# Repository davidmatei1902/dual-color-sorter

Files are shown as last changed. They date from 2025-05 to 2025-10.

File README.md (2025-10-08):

# Dual Color Sorter

An automated conveyor-belt system that classifies objects by color (e.g., orange or blue) and redirects them using a motorized paddle. This educational prototype uses an ultrasonic distance sensor and a color sensor to detect, classify, and sort objects in real time.

## Overview

The Dual Color Sorter is a microcontroller-based prototype that demonstrates the core principles of automated sorting in logistics and manufacturing. It uses basic sensors and actuators controlled by an Arduino Uno to classify and redirect small objects based on color.

## Features

- **Automatic object sorting** based on detected color
- **Color classification** using the TCS230 sensor (default: orange vs. blue)
- **Ultrasonic object detection** with HC-SR04
- **Motorized paddle** for redirection (left for orange, right for blue)
- **Continuous loop logic** with a start/stop button
- **Modular and educational design**, suitable for prototyping and teaching

## Hardware Components

| Component | Description |
|---|---|
| Arduino Uno | Main microcontroller |
| TCS230 | Color sensor for RGB color detection |
| HC-SR04 | Ultrasonic sensor for object presence detection |
| GA12-N20 DC Motors  | Drives both the conveyor belt and paddle mechanism |
| L298N Motor Driver  | Dual H-bridge to control DC motors |
| LM2596 Buck Converter | Power regulation (6V from 9V battery) |
| Conveyor Belt | Transports objects through the system |
| Power Supply | Two 9V batteries |

##   Project Overview

<p align="center">
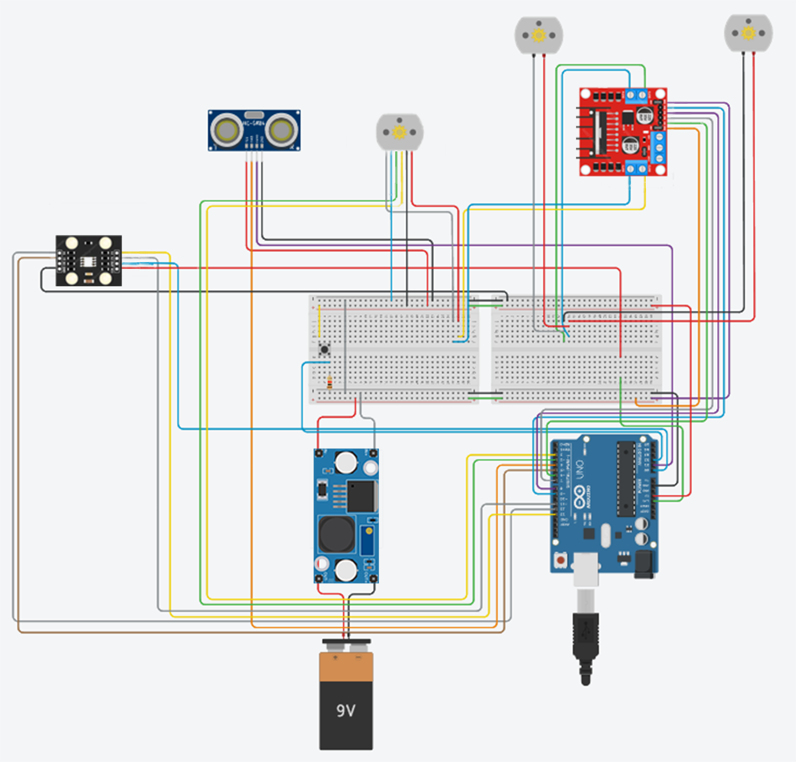
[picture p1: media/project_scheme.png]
Project Overview
  
</p>

<p align="center"><em>Figure : Overview of the Dual Color Sorter system, showing its components and layout.</em></p>

## How It Works

1. The user presses a button to start the conveyor belt.
2. An object is detected by the ultrasonic sensor.
3. The conveyor belt stops once the object reaches the color detection zone.
4. The TCS230 sensor reads the object's color.
5. The Arduino compares the RGB values to reference data:
   - If **orange**, the paddle redirects the object to the left.
   - If **blue**, the paddle redirects it to the right.
6. The belt pauses briefly, then resumes for the next object.

This cycle repeats for continuous sorting.

## Calibration

The color sensor is calibrated in four steps:
1. Place the sensor on a **white** surface and press the button.
2. Repeat for **black**, **blue**, and **orange** surfaces.
3. The system stores RGB thresholds and calculates distances to identify color in real-time.

## Pseudocode Logic

```plaintext
Function setup:
    Initialize pins

Function loop:
    Calculate how long the button was pressed
    if pressed time < 2s:
        if not in calibration mode:
            if system is off:
                Turn on system
            else:
                Turn off system
        else:
            Process calibration step
    else:
        Start calibration mode

    if system is on:
        Start conveyor belt
        Calculate distance to object
        if object reached paddle area:
            Stop conveyor belt
            Detect color
            if color is orange:
                Rotate paddle left
            else if color is blue:
                Rotate paddle right
            else:
                Resume conveyor belt
    else:
        Stop conveyor belt
```

## Technical Specifications

- **Conveyor Dimensions:** 26 × 4 × 4 cm
- **System Dimensions:** 54 × 25 × 24 cm (closed), 75 × 68 × 24 cm (open)
- **Max Object Size:** 3 × 3 × 4 cm
- **Power Supply:** 2 × 9V batteries
- **Operating Temperature:** 10–40°C
- **Estimated Power Consumption:** 35W

## Authors

- **Badea Cătălin-Gabriel** — Hardware design, 3D modeling, wiring, documentation
- **Atudosiei Andrei Cristian** — Firmware development, calibration algorithm, optimization
- **Matei David** — Circuit integration, assembly, component sourcing, video editing

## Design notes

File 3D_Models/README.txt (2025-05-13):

It is possible that the models in the 
folder are not at an absolutely perfect scale, 
as they may have been slightly adjusted—either 
during export or within the printer's software.

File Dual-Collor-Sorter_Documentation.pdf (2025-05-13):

# Dual Color Sorter

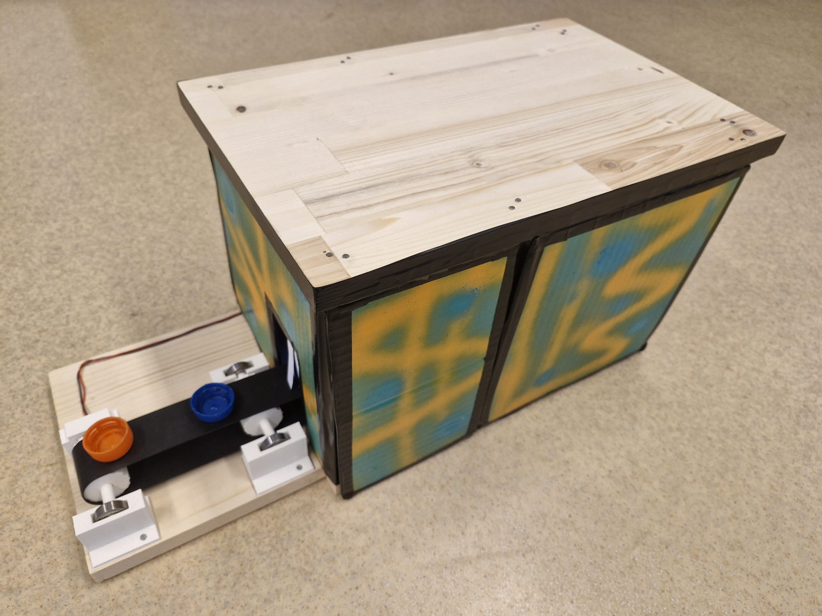
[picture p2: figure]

Abstract

This project presents an automated object sorting system implemented with a conveyor belt. The system is designed to identify and sort objects based on their color (orange or blue) using a combination of an ultrasonic distance sensor and a color sensor. A paddle mechanism redirects objects to appropriate paths based on their detected color. This document outlines the design, implementation, and testing of the system, along with its potential applications in industrial automation.

Authors:
Badea C˘at˘alin-Gabriel, Matei David, Atudosiei Andrei Cristian

Date: May 2025

Color Sorter Project | Badea Gabriel, Atudosiei Andrei, Matei David

## Contents

1 Domain Overview | 3
2 Project Objectives | 5
3 Implementation | 6
4 Testing and Calibration | 11
5 Problems Encountered | 12
6 Potential Improvements and Future Extensions | 13
7 Conclusion | 14

## 1 Domain Overview

### 1.1 Introduction

The domain of this project is firmly situated within intelligent transportation systems (ITS), with a specific focus on automated object classification and routing. This system demonstrates the principles of smart logistics by using a conveyor belt to sort objects based on their color—specifically identifying and separating orange and blue items.
By integrating basic color-based classification, the system mimics intelligent transport technologies where real-time decisions are made based on sensor input. This leads to improved accuracy, reduced manual intervention, and increased efficiency in the handling and routing of physical items within broader transportation and logistics frameworks.

### 1.2 The Importance of Sorting Systems

Sorting systems are fundamental to the efficient handling and management of data, objects, and processes across a wide range of industries. Whether applied in computer science, logistics, manufacturing, or administration, an effective sorting mechanism improves clarity, reduces processing time, and enhances user experience.
By organizing elements based on defined criteria—such as alphabetical order, numerical value, priority, or category—sorting enables faster retrieval, better data analysis, and streamlined operations. In large-scale systems, such as databases or automated warehouses, sorting becomes critical for performance optimization and scalability.
Moreover, it contributes to error reduction and supports automation by establishing a predictable structure. As the amount of information and complexity of workflows continue to grow, the role of sorting systems becomes increasingly vital for ensuring order, efficiency, and informed decision-making.

### 1.3 Similar Existing Solutions

Modern industrial sorting systems increasingly rely on advanced technologies to improve accuracy, speed, and flexibility. Table 1 highlights some of the most commonly used methods and their applications.

Technology | Application
Machine vision | Cameras and image processing for sorting based on color, shape, or size
AI and machine learning | Pattern recognition for complex or variable sorting tasks
RFID technology | Wireless identification and sorting of tagged items

Table 1: Advanced technologies in industrial sorting systems

These technologies are widely used in industries such as manufacturing, recycling, and logistics. Machine vision handles visual analysis, AI enables smarter decisions based on learned patterns, and RFID offers efficient tracking and categorization without visual input.

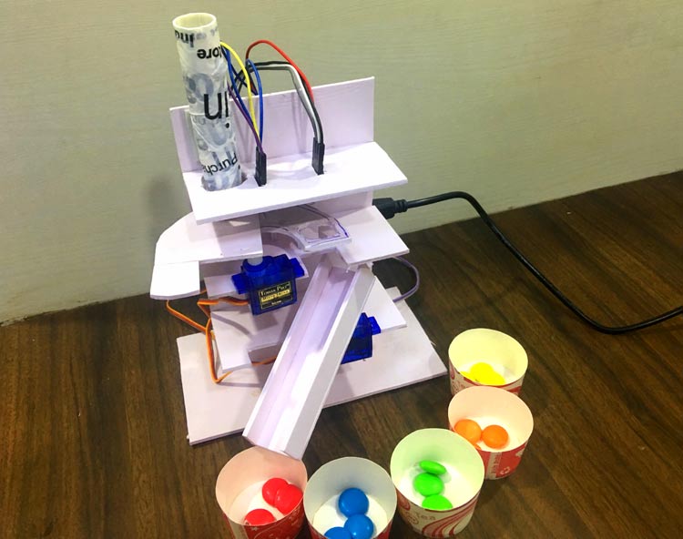
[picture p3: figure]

Figure 1: Multiple Color Sorter System Machine

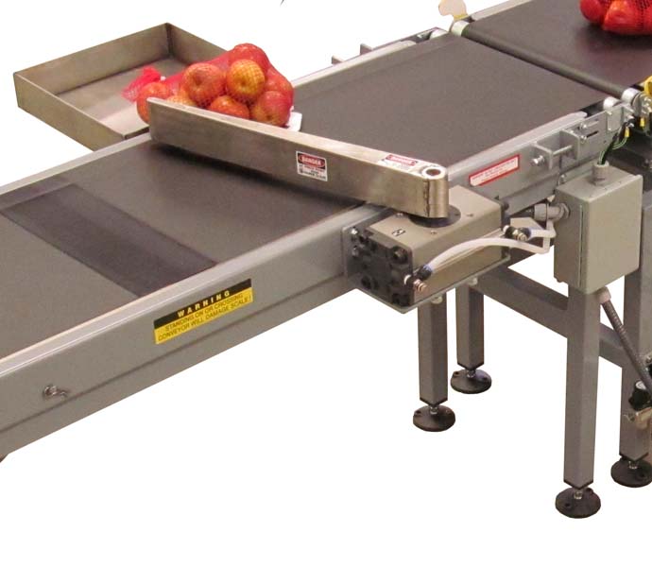
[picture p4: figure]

Figure 2: Apple Sorter with Mechanical Redirectors

### 1.4 Our Approach

Our approach is a simplified prototype inspired by industrial sorting systems. While commercial systems rely on advanced technologies, our focus is on color-based sorting using basic sensors and mechanical actuation.
Created as a didactic prototype, this system aims to teach and experiment with the core principles of automated sorting. Using an ultrasonic sensor for detection and a color sensor for classification, objects are sorted based on their color, with a DC motor controlled paddle redirecting them accordingly.
Though simpler than industrial solutions, our approach serves as a foundation for learning and exploring automated sorting concepts. Furthermore, the colored objects used in this project can simulate containers or casings for items of interest, such as pills, electronic components, or food products. This abstraction allows the system to be relevant in various practical scenarios, including pharmaceutical packaging, component assembly lines, or quality control in food processing. However, the current paddle-based mechanism might be better replaced with a gentler alternative to avoid damaging sensitive items.

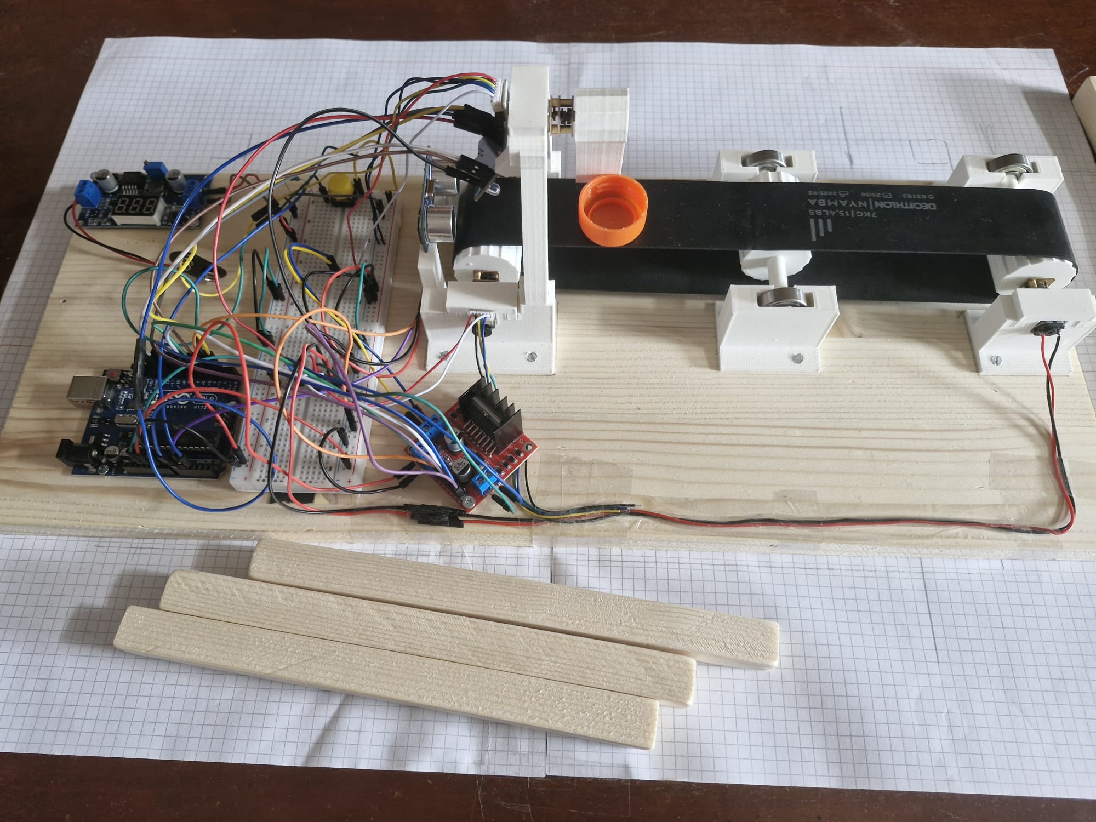
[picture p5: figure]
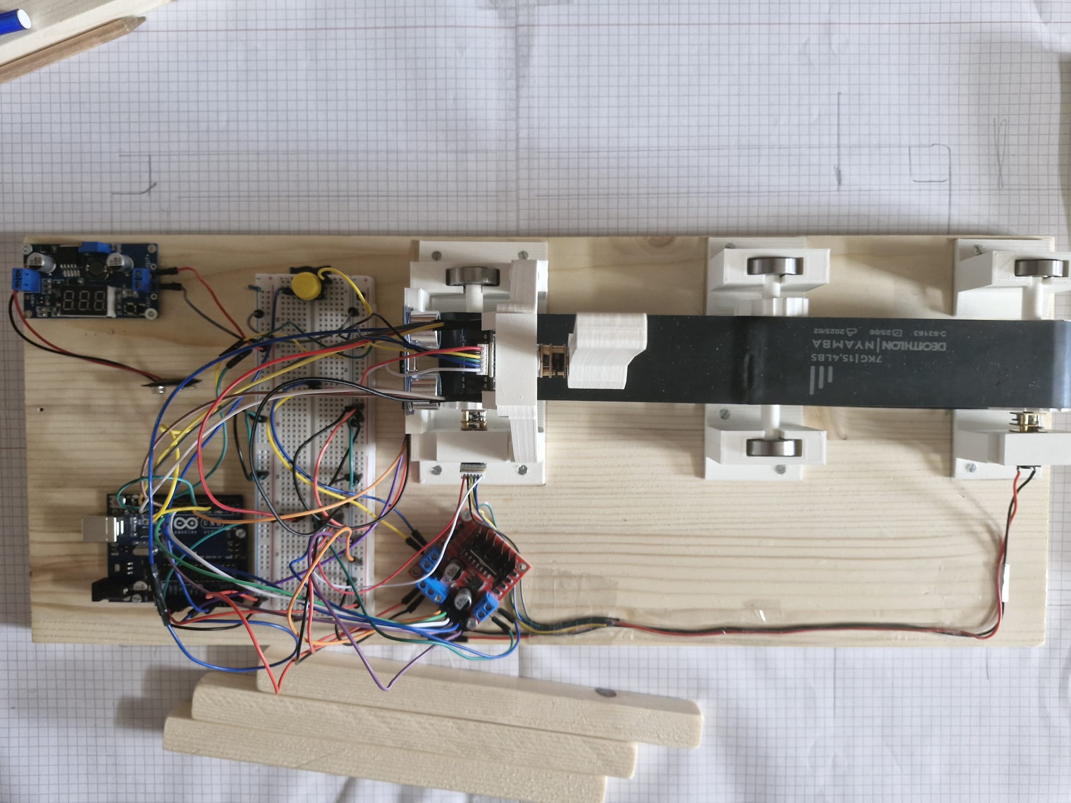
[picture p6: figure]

Figure 3: Wiring Closer View | Figure 4: Wire Top View

## 2 Project Objectives

The development of our automated object sorting system is guided by the following key objectives:

Objective 1: Conveyor-Based Transport System Development

- Design and implement a reliable conveyor belt mechanism
- Ensure smooth and consistent object movement
- Configure appropriate speed for accurate detection and sorting

Objective 2: Precise Color Detection Implementation

- Integrate the TCS230 color sensor for accurate color identification
- Develop algorithms to differentiate between orange and blue objects
- Calibrate the sensor for optimal performance under varying lighting conditions

Objective 3: Automated Object Redirection Mechanism

- Design an efficient paddle actuation system
- Program the rotary motor for precise angular positioning using an encoder
- Ensure reliable sorting with minimal errors

Objective 4: Synchronized Process Control

- Implement the HC-SR04 ultrasonic sensor for accurate object detection
- Create timing sequences for coordinated operation of all system components
- Develop robust control logic for continuous operation

Objective 5: System Optimization and Performance Validation

- Conduct comprehensive testing under operational conditions
- Measure and improve sorting accuracy rates
- Fine-tune timing parameters for maximum throughput

These objectives serve as the foundation for developing a functional, efficient, and reliable color sorting system applicable to small-scale industrial environments where rapid and precise object handling is required.

## 3 Implementation

### 3.1 General Description

The project consists of an automated object sorting system on a conveyor belt, designed to sort two types of colors, which can be configured depending on the system’s calibration. Although the system can be adjusted to detect and sort any two colors, throughout this project we will focus on the case of sorting orange and blue objects.
The system operates through the following process:

### 1. Pressing a button activate/deactivates the conveyor belt, which is powered by two

motors and moves objects smoothly along its path.

### 2. Objects reach a detection zone where an HC-SR04 ultrasonic distance sensor is

positioned.

### 3. When an object reaches the predetermined distance threshold, the belt automat-

ically stops.

4. The TCS230 color sensor identifies its color.

### 5. Based on the detected color, a paddle operated by another GA12 N20 6V motor

redirects the object:

- Orange objects are directed to the left path
- Blue objects are directed to the right path

### 6. After redirection, the system pauses for approximately ? second to ensure com-

plete processing.

7. The conveyor belt resumes operation to transport the next object.

This automated cycle continues, enabling efficient and precise sorting of objects by color. The system’s design emphasizes simplicity and reliability.

### 3.2 System Components

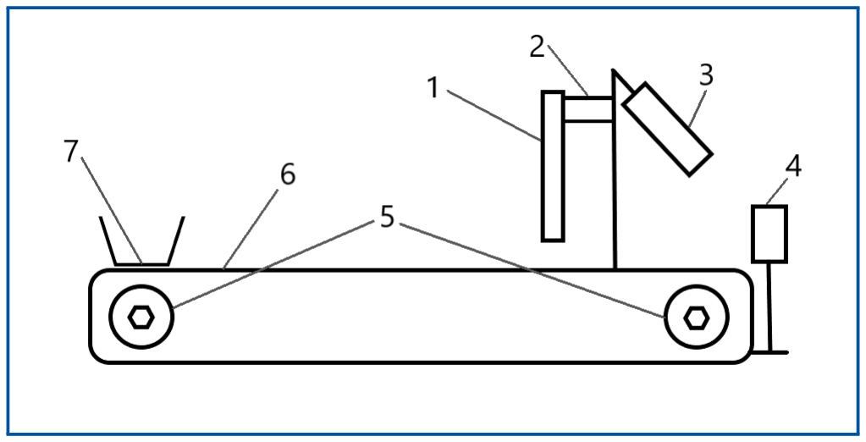
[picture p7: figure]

Figure 5: Structure Diagram

Above, a diagram outlines the structure of the project and below there is a list of the components used, along with a table regarding the key system components and their functions.

No. | Component Name
1 | Paddle
2 | DC-motor (Paddle Controller)
3 | Color Sensor
4 | Distance Sensor
5 | DC-motors (Belt Controllers)
6 | Conveyor Belt
7 | Object to be sorted

Table 2: List of system components by number and name

Component | Type/Model | Function
Conveyor Belt | Dual-motor driven | Transports objects through the sorting system
Distance Sensor | HC-SR04 Ultrasonic | Detects object presence and stops the conveyor belt in the right position
Color Sensor | TCS230 | Identifies the color of objects (orange vs. blue), sending the signal to the microcontroller
Motor Driver | L298N | Dual H-bridge driver for controlling both the conveyor belt and paddle DC motors
Buck Convertor | LM2596 | Adjustable step-down (buck) converter that pro- vides a stable 6V supply from the 9V battery
Actuators | 3 × GA12-N20 6V DC-motor | Controls the paddle for object redirection as well
| | as the conveyor belt
Control Unit | Arduino UNO Microcontroller | Processes sensor data and controls system com- ponents
Power Supply | 2 × 9V Battery | Provides electrical power to all system compo-
| | nents, including the conveyor belt

Table 3: Key system components and their functions

Note that the box can be opened on any side, except for the front, to provide easy access to the circuits and wires inside. This design allows for convenient maintenance and modifications, ensuring that all components are accessible without disturbing the main structure of the system.

### 3.3 Electrical Circuit Design

In this section, the electrical circuit design of the sorting system is presented. The system utilizes multiple components that work together to process data and control the actuators for object sorting. Below is a simplified block diagram that shows how these components are interconnected.
At the core of the system is the Arduino microcontroller, which processes data from the sensors and controls the actuators. The ultrasonic distance sensor is connected to the Arduino and is powered with 5V from it. The color sensor is also connected to the Arduino, but it operates at 3.3V. The Arduino controls the motors through an H-bridge. The H-bridge drives two motors that control the conveyor belt simultaneously and one motor for the paddle mechanism, which redirects the objects. The motors are powered with 6V from a buck converter, which steps down the 9V battery supply to 6V (the operating voltage of the motors). The Arduino itself is powered by a separate 9V battery to ensure proper functionality and to prevent the higher current draw from the motor line from damaging the microcontroller.
The block diagram below illustrates the overall flow of power and control signals within the system.

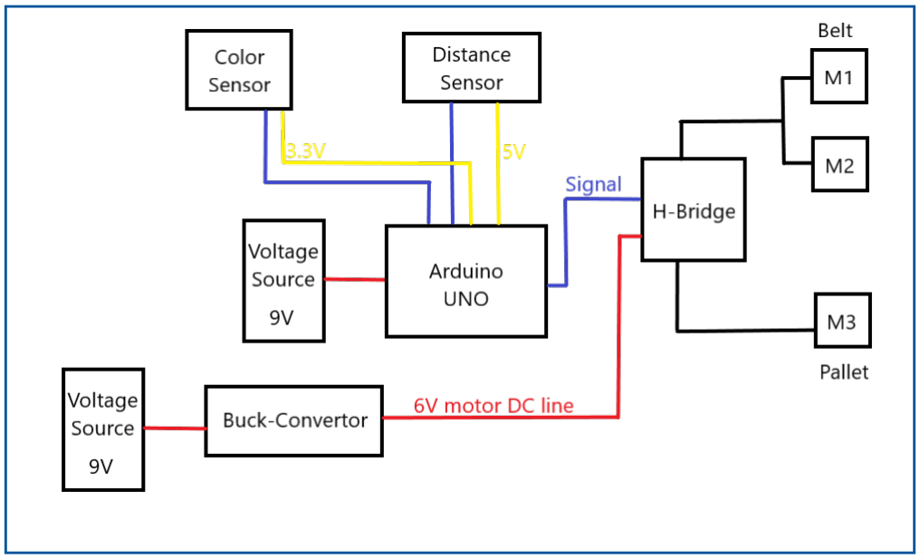
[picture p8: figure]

Figure 6: Block diagram of the sorting system

Following this section, the detailed circuit schematic is provided, showing the exact wiring of each component and how they are physically connected to one another.
It is important to note that the circuit includes a button designed to stop the conveyor belt, allowing for debugging or turning off the system when not in use.


Figure 7: Detailed wiring diagram of the system

### 3.4 Technical Specifications

Parameter | Specification
Conveyor Length/Width/Height | 26 cm / 4 cm / 4 cm
Total System Dimensions | 54 cm x 25 cm x 24 cm (L x W x H)
Total System Dimensions Needed (open) 75 cm x 68 cm x 24 cm (L x W x H)
Maximum Object Size | 3 cm × 3 cm × 4 cm
Power Consumption | 35W
Operating Temperature | 10-40°C
Power Supply | 2 x 9V Battery

Table 4: System technical specifications

### 3.5 Programming and Microcontroller Code

In this section, the programming logic of the sorting system is presented, focusing on the microcontroller code. The Arduino is responsible for processing the data from the sensors, making decisions based on the input, and controlling the actuators to sort the objects.
The code is written in C++ using the Arduino IDE, and it communicates with the various system components, including the ultrasonic distance sensor, color sensor, and motors. Algorithm 1: Main logic for the color sorting system
1 setup Initialize pins;
2 loop Calculate how long the button was pressed;

### 3 if pressed time less than 2s then 4 if not in calibration mode then 5 if system is off then

6 Turn on system;

### 7 else

8 Turn off system;

### 9 end 10 else

11 Process calibration step;

### 12 end 13 else

14 Start calibration mode;

### 15 end 16 if system is on then

17 Start conveyor belt;
18 Calculate distance to object;

### 19 if object reached paddle area then

20 Stop conveyor belt;
21 Detect color;

### 22 if color is orange then

23 Rotate paddle left;

### 24 else 25 if color is blue then

26 Rotate paddle right;

### 27 else

28 Resume conveyor belt;

### 29 end 30 end 31 end 32 end 33 else

34 Stop conveyor belt;

### 35 end

This code is a basic framework for reading sensor data and triggering actions based on specific conditions.

## 4 Testing and Calibration

### 4.1 TCS230 Color Detector

### 4.1.1 Calibration Process Structure

Calibration is divided into four stages: white, black, blue, and orange.

- Stage 1 (White): The user places the sensor on a white surface and presses the button. The system reads the Red, Green, and Blue values and stores them in variables. After a short button press, it advances to the next stage.
- Stage 2 (Black): The user places the sensor on a black surface and presses the button. The system reads and saves the RGB values. After a short press, it moves on.
- Stage 3 (Blue): The user places the sensor on a blue surface and presses the button. The system reads and saves the RGB values. Then proceeds.
- Stage 4 (Orange): The user places the sensor on an orange surface and presses the button. The system reads and saves the RGB values. Calibration is then complete.

### 4.1.2 Setting Color Thresholds

For each color component (Red, Green, Blue), the minimum and maximum thresholds are calculated from the white and black readings:

Red: pragRosuMin, pragRosuMax

Green: pragVerdeMin, pragVerdeMax

Blue: pragAlbastruMin, pragAlbastruMax

Values outside these ranges are considered “unknown.”

### 4.1.3 Color Distance Calculation

During object detection, the system compares the sensed RGB values to the calibrated blue and orange references using:

distance = (r1 − r2)

2 + (g1 − g2)

2 + (b1 − b2)

2

If the distance to orange is less than the distance to blue, the color is detected as orange; otherwise it is detected as blue.

### 4.1.4 Calibration Completion

After all four stages, the flag senzorCalibrat = true is set and the user is notified. The system is now ready for normal operation.

### 4.2 HC-SR04 Ultrasonic Sensor

To test the HC-SR04, a simple Arduino sketch triggers the sensor continuously, measures the echo return time, computes the distance, and prints the results to the serial monitor. Real-time readings allow verification of the sensor’s accuracy.

### 4.3 DC Motors

### 4.3.1 Basic DC Motor Test

An Arduino sketch was used to spin the motors first in one direction and then in reverse, confirming proper wiring and operation.

### 4.3.2 DC Motor with Encoder (CGM12-N20VA-8200E)

For precise one-revolution control, the encoder’s pulse count per full rotation was calibrated:

Encoder Overview The encoder emits pulses (“ticks”) proportional to shaft rotation.

Estimating Pulses per Revolution Based on the motor’s gear ratio and encoder spec, an initial pulse estimate was made.

Testing and Adjustment A sketch rotated the motor while counting ticks. After each trial, the pulse count was tweaked until one commanded revolution matched one full turn.

Finalizing Calibration The correct tick count was hard-coded into the program so that each “full revolution” command yields precise rotation.

## 5 Problems Encountered

During the development of our project, we encountered a series of technical and practical challenges that required iterative problem-solving and adaptation. Below is a summary of the most significant issues and how we addressed them:

- Color sensor instability: Initially, the color sensor did not function reliably. We discovered it was extremely sensitive to minor changes in ambient lighting. To address this, we built a small enclosure around it to maintain consistent lighting conditions.
- Encoder setup difficulties: It took us some time to properly understand and use the rotary encoder. One of the main issues was that it only worked correctly when connected to pins 2 and 3 of the Arduino, which limited our initial wiring options.
- Circuit redesign: We had to completely rebuild the circuit once in order to optimize pin usage. This allowed us to support all the required functionalities more effectively.
- Power supply decision: Finding a suitable power supply was a challenge. In the end, we chose to use a battery, as it offered a more compact and portable solution, and it fit the educational purpose of the project.
- 3D printing issues: The 3D-printed parts did not always match the exact dimensions due to plastic expansion and shrinkage. As a result, we had to reprint several components before achieving the desired fit and functionality.
- Belt selection: It took us some time to find a belt that was suitable for our design and functional requirements.

## 6 Potential Improvements and Future Extensions

While the current prototype demonstrates the core principles of automated color-based sorting, there are several clear avenues to enhance its performance, flexibility and educational value. Key directions for future work include:

- Advanced Color Detection: Upgrade from a simple color sensor to a multi-channel spectral sensor (e.g. TCS34725) or integrate a camera + OpenCV pipeline to sort dozens of hues and even shapes.
- LCD Feedback Display: Integrate an LCD module to present real-time calibration progress—showing each stage (white, black, blue, orange)— as well as continuously display the detected color along with a running count of how many times each color has been identified.
- Modular Mechanical Design: Design interchangeable paddles, adjustable guide rails and expandable conveyor segments to handle different object sizes or multiple lanes in parallel.
- Power Management: Move from 9V batteries to rechargeable Li-ion packs or a smart buck/boost converter with voltage/current monitoring and power-saving modes.

For a future version of the system (v2.0), an important improvement would be the addition of a second sorting paddle mounted on a separate support arm. This would enable the system to handle up to four distinct object categories based on color, instead of the current binary classification.

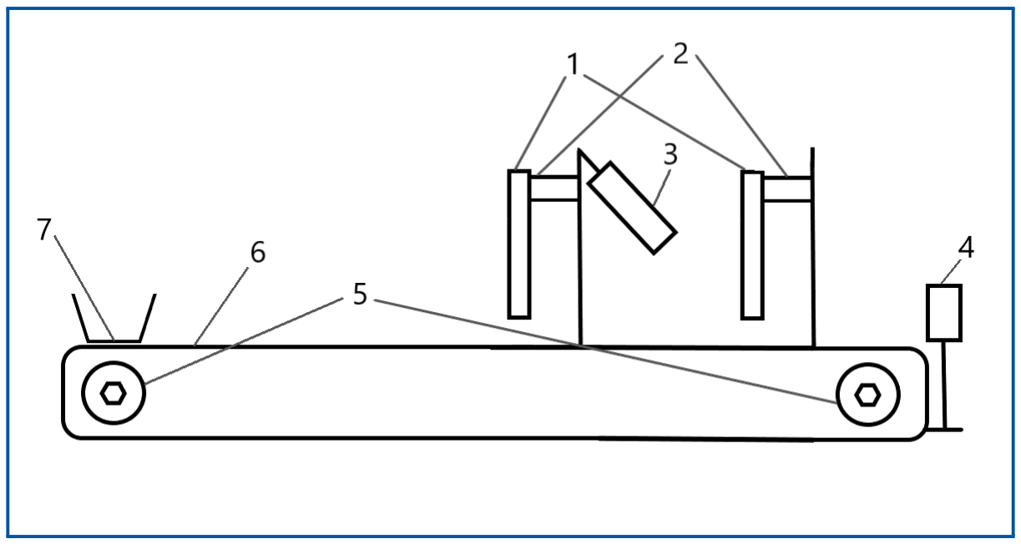
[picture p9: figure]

Figure 8: Structure Diagram V2.0

Furthermore, we considered replacing the battery-based power supply with a stable external power source to ensure longer operating times and improved reliability.
However, due to time constraints and prototyping limitations, these enhancements were not implemented in the current iteration.

## 7 Conclusion

The automated color sorting system successfully demonstrates the application of sensor technology and mechanical actuation. The system reliably sorts orange and blue objects with high accuracy and reasonable throughput.

### 7.1 Individual Contributions

Badea C˘at˘alin-Gabriel:

- Coordonated the whole project
- Designed the circuit and structure of the machine
- Modeled and 3D-printed the support pieces
- Worked on wiring the circuit
- Worked on building and painting the structure of the machine
- Contributed to documentation

Atudosiei Andrei Cristian:

- Developed the code uploaded on the microprocessor
- Color detection algorithm development
- Sensor calibration
- Performance optimization and debugging
- Contributed to documentation

Matei David:

- Documented the schematic
- Worked on wiring the circuit
- Worked on building and painting the structure of the machine
- Purchased and supplied all the components required
- Contributed to documentation
- Edited the video regarding the project completion

### 7.2 Bill Of Materials

Listed below are all the components used in the realization and assembly of the automated sorting system, together with their prices and sources of acquisition.

Item | Part Number / Model | Qty | Total (e) Supplier
1. | Rubber Band | 1 | 3.52 | Decathlon (https://www.decathlon.ro/p/set-3-mini-benzi-elastice-din-cauciuc-100/_/R-p-305336)
2. | HC-SR04 | 1 | 2.93 | ElecFreaks (https://www.optimusdigital.ro/en/ultrasonic-sensors/2328-senzor-ultrasonic-de-distana-hc-sr04-compatibil-33-v-i-5-v.html)
3. | TCS230 | 1 | 7.62 | TAOS (https://www.optimusdigital.ro/en/optical-sensors/111-tcs230-color-sensor-module.html)
4. | GA12-N20 with Encoder | 2 | 20.32 | Handson Technology (https://www.optimusdigital.ro/ro/motoare-micro-motoare-cu-reductor/2937-micro-motor-cu-reductor-i-codor-cgm12-n20va-8200e-52-rpm-la-3-v-105-rpm-la-6-v.html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)
5. | GA12-N20 | 1 | 5.11 | Handson Technology (https://www.emag.ro/micro-motor-cu-reductie-dc-6v-30rpm-ga12-n20-ai1083/pd/DVWFTFMBM/)
6. | Arduino Board A000066 | 1 | 11.60 | OptimusDigital (https://www.optimusdigital.ro/en/avr-boards/4561-development-board-compatible-with-arduino-uno-r3-atmega328p-atmega16u2-50-cm-cable.html)
7. | Jumper Wires (Male–Male) | 18 | 1.10 | OptimusDigital (https://www.optimusdigital.ro/en/wires-with-connectors/891-wires-male-male-10p-30cm.html)
8. | Jumper Wires (Male–Female) | 26 | 0.72 | OptimusDigital (https://www.optimusdigital.ro/en/wires-with-connectors/650-fire-colorate-mama-tata-10p.html)
9. | Battery Holder 9V | 1 | 0.28 | OptimusDigital (https://www.optimusdigital.ro/en/battery-holders/20-9v-battery-support.html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)
10. | Through-Hole Resistor 470 Ohm | 1 | 0.02 | OptimusDigital (https://www.optimusdigital.ro/en/resistors/852-025w-470k-resistor.html?search_query=resistor&results=367)
11. | Tactile Push-Button | 1 | 0.43 | OptimusDigital (https://www.optimusdigital.ro/en/buttons-and-switches/1115-white-button-with-round-cover.html)
12. | Power Cable | 1 | 0.76 | XAB3 (https://www.xab3.ro/produse/332cablu-alimentare-arduino)
13. | Bearing 608-2Z Welt | 4 | 4.00 | Herasib (https://www.emag.ro/rulment-608-2z-welt-608-2z-welt/pd/D2SPMDMBM/)
14. | High Performance Battery 9V | 2 | 4.48 | Auchan (https://www.auchan.ro/baterie-alcalina-auchan-high-performance-6lr61-9v-1-bucata/p)
15. | L298N - H-Bridge | 1 | 2.72 | Optimus Digital (https://www.optimusdigital.ro/en/brushed-motor-drivers/145-l298n-dual-motor-driver.html)
16. | LM2596 - Buck Convertor | 1 | 1.00 | Texas Instruments (https://www.optimusdigital.ro/en/adjustable-step-down-power-supplies/805-lm2596-dc-dc-module-with-voltage-display.html)
17. | Verbatim PLA 1.75 mm (750 g) | 1 | 25.00 | Verbatim (https://www.flax.ro/filament-verbatim-pla-1-75mm-1kg-natural-55317-356643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)
18. | Plywood Base | 1 | 3.92 | Leroy Merlin (https://www.leroymerlin.ro/produse/grinzi-lemn/1631/scandura-nerindeluita-lemn-rasinoase-24-x-200-x-4000-mm/122722)
19. | Plywood Poles | 1 | 3.92 | Leroy Merlin (https://www.leroymerlin.ro/produse/grinzi-lemn/1631/rigla-rindeluita-lemn-rasinoase-42-x-42-x-2000-mm/13644)
20. | Plywood Roof | 1 | 4.9 | Leroy Merlin (https://www.leroymerlin.ro/produse/polite-din-pal-lemn/1252/polita-lemn-rasinoase-calitatea-b-800-x-300-x-18-mm/96106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)
19. | Nails | 32 | 0.82 | Leroy Merlin (https://www.leroymerlin.ro/produse/cuie/939/cuie-lemn-3-x-50-mm-1-kg/125857)
19. | Screws | 21 | 1.008 | Leroy Merlin (https://www.leroymerlin.ro/produse/suruburi/942/surub-lemn-cap-inecat-otel-zincat-4.5-x-20-mm-vrac/36231)

Table 5: Bill of Materials

## Total Price: 90.048 e

## References

[1] Electronic | Principles | (Malvino) – https://www.talkingelectronics.com/
Download/Malvino_Electronic-Principles.pdf (https://www.talkingelectronics.com/Download/Malvino_Electronic-Principles.pdf)
[2] Ultrasonic Sensor HC-SR04 and Arduino – Complete Guide – https://howtomechatronics.com/tutorials/arduino/ultrasonic-sensor-hc-sr04/
[3] Good Year Industrial Conveyor Belt - https://goodyearbelts.com/wp-content/uploads/2024/02/New-Industrial-Catalog-2024-FINAL.pdf (https://goodyearbelts.com/wp-content/uploads/2024/02/New-Industrial-Catalog-2024-FINAL.pdf)
[4] Contitech Lightweight Conveyor Belt https://www.goodyearbelting.com/pdf/Contitech_2015_LW_Conv_Belt_Catalog/pdf/Contitech_2015_LW_Conv_Belt_Catalog.pdf (https://www.goodyearbelting.com/pdf/Contitech_2015_LW_Conv_Belt_Catalog/pdf/Contitech_2015_LW_Conv_Belt_Catalog.pdf)

Technical datasheets for every component used in this project are listed below:

[5] HC-SR04 – https://cdn.sparkfun.com/datasheets/Sensors/Proximity/HCSR04. pdf (https://cdn.sparkfun.com/datasheets/Sensors/Proximity/HCSR04.pdf)
[6] TCS230 – https://www.mouser.com/datasheet/2/588/cs230-e33-1214740.pdf
[7] GA12-N20 6V DC Motor – https://www.handsontec.com/dataspecs/GA12-N20. pdf (https://www.handsontec.com/dataspecs/GA12-N20.pdf)
[8] Arduino | Uno | Microcontroller | – | https://docs.arduino.cc/resources/
datasheets/A000066-datasheet.pdf (https://docs.arduino.cc/resources/datasheets/A000066-datasheet.pdf)
[9] 9V Battery (Energizer 522) – https://data.energizer.com/pdfs/522.pdf
[10] Conveyor Belt Catalog (Goodyear, 2024) – https://goodyearrubberproducts.lat/wp-content/uploads/2024-GRP-Conveyor-Belt-Catalog.pdf (https://goodyearrubberproducts.lat/wp-content/uploads/2024-GRP-Conveyor-Belt-Catalog.pdf)
[11] L298N Module – https://www.alldatasheet.com/datasheet-pdf/view/22440/STMICROELECTRONICS/L298N.html (https://www.alldatasheet.com/datasheet-pdf/view/22440/STMICROELECTRONICS/L298N.html)
[12] LM2596 Module – https://www.ti.com/lit/ds/symlink/lm2596.pdf

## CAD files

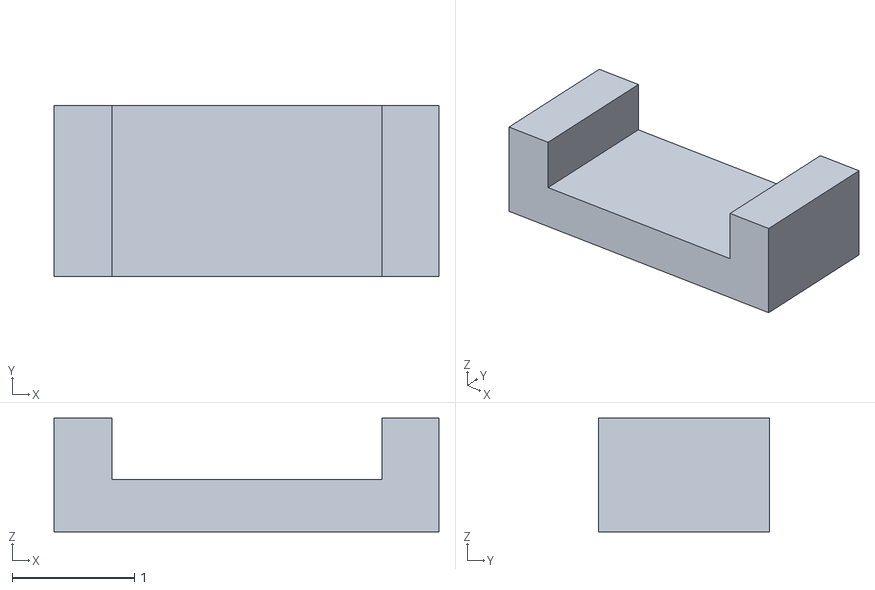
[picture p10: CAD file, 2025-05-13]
3D_Models/clamp.stl
3.16 x 1.40 x 0.931

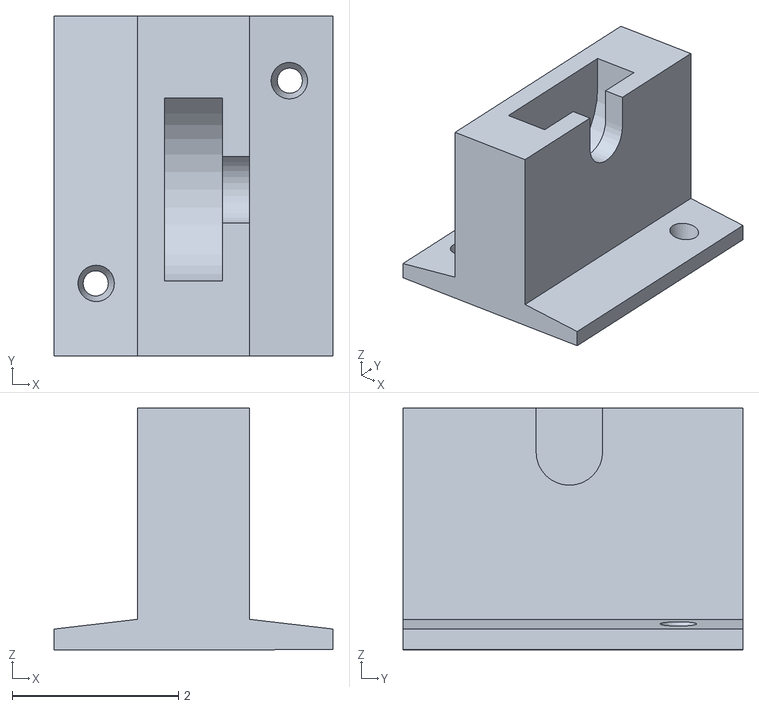
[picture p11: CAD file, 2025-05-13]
3D_Models/structural_frame_1.stl
3.36 x 4.09 x 2.91

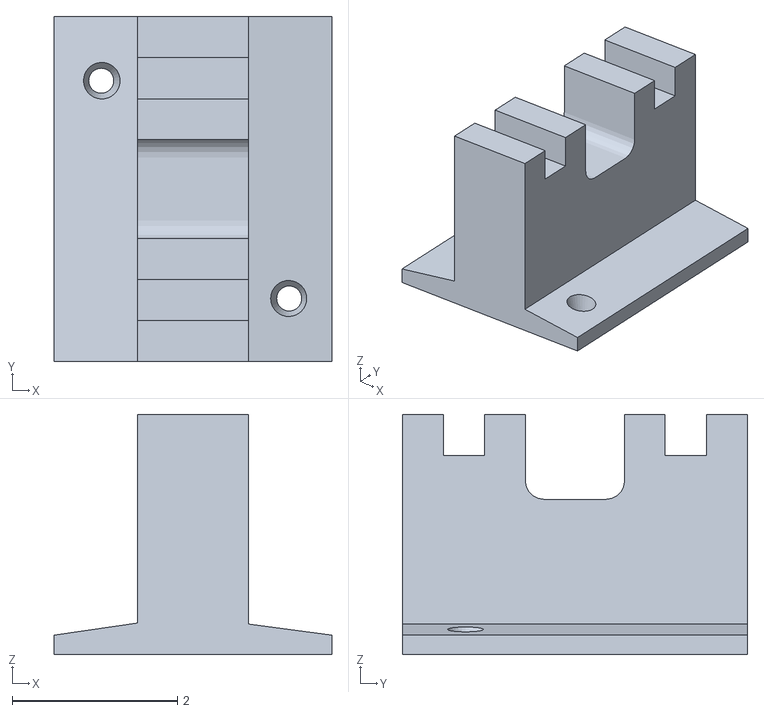
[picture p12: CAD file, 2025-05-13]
3D_Models/structural_frame_2.stl
3.36 x 4.18 x 2.91

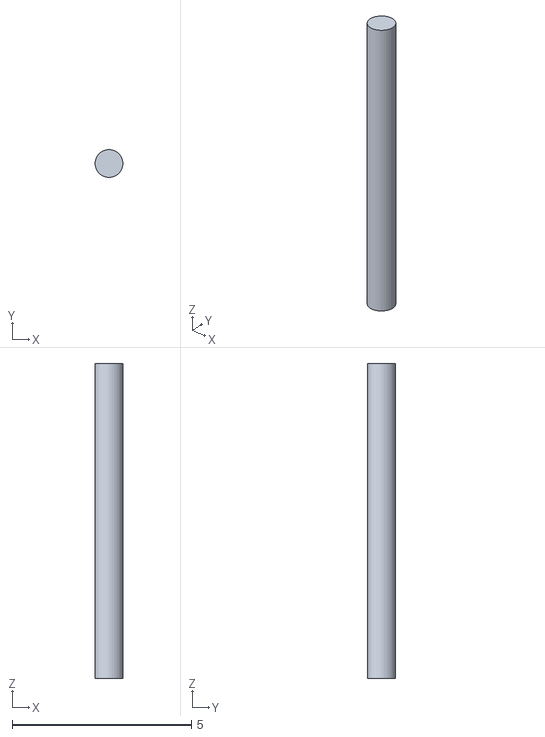
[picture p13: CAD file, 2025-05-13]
3D_Models/shaft_long.stl
0.779 x 0.779 x 8.78

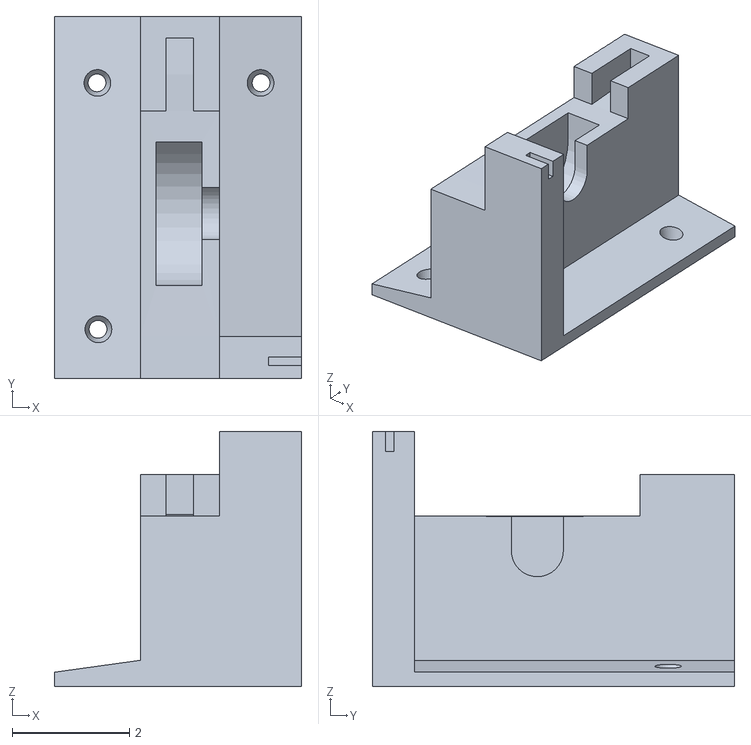
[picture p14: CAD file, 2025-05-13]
3D_Models/structural_frame_3.stl
4.21 x 6.16 x 4.34

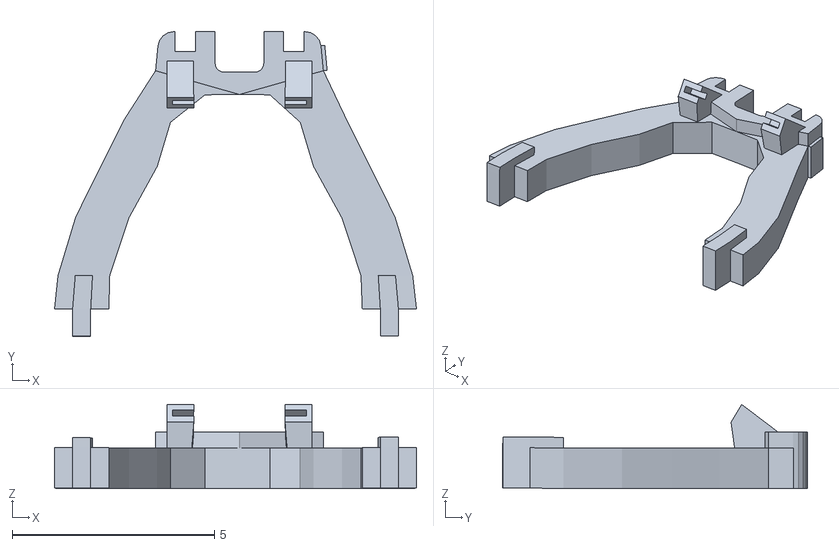
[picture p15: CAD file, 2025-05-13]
3D_Models/ark_support.stl
8.94 x 7.53 x 2.08

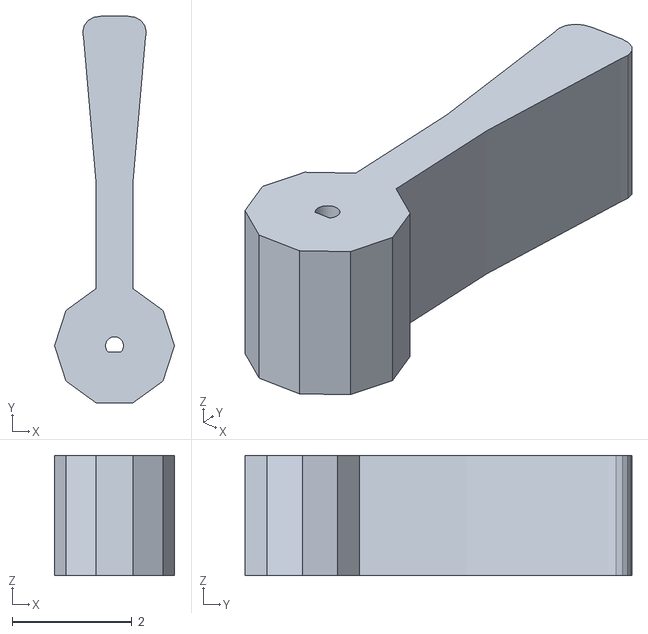
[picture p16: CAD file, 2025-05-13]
3D_Models/peddle.stl
2.00 x 6.44 x 2.00

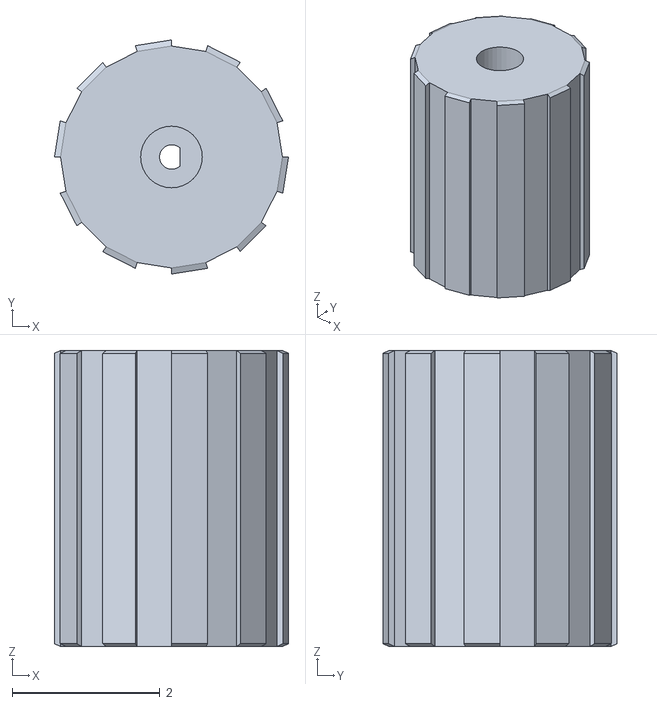
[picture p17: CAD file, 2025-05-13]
3D_Models/tube_support.stl
3.16 x 3.16 x 4.00

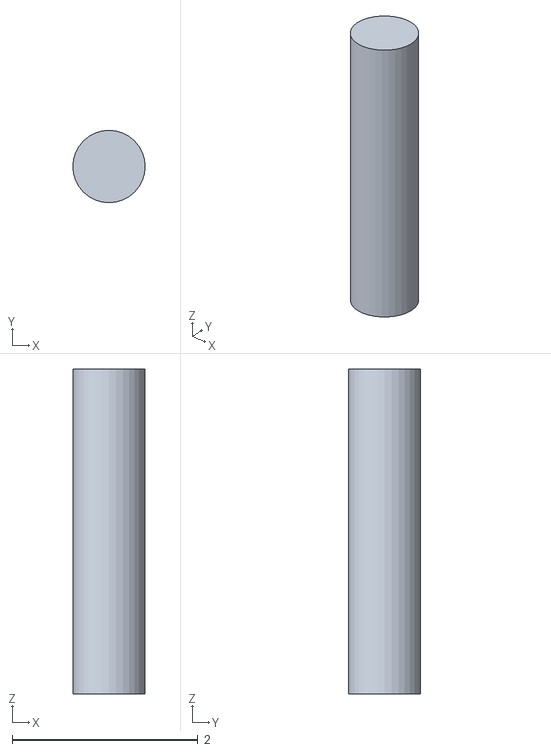
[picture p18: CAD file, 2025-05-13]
3D_Models/shaft_short.stl
0.779 x 0.779 x 3.50

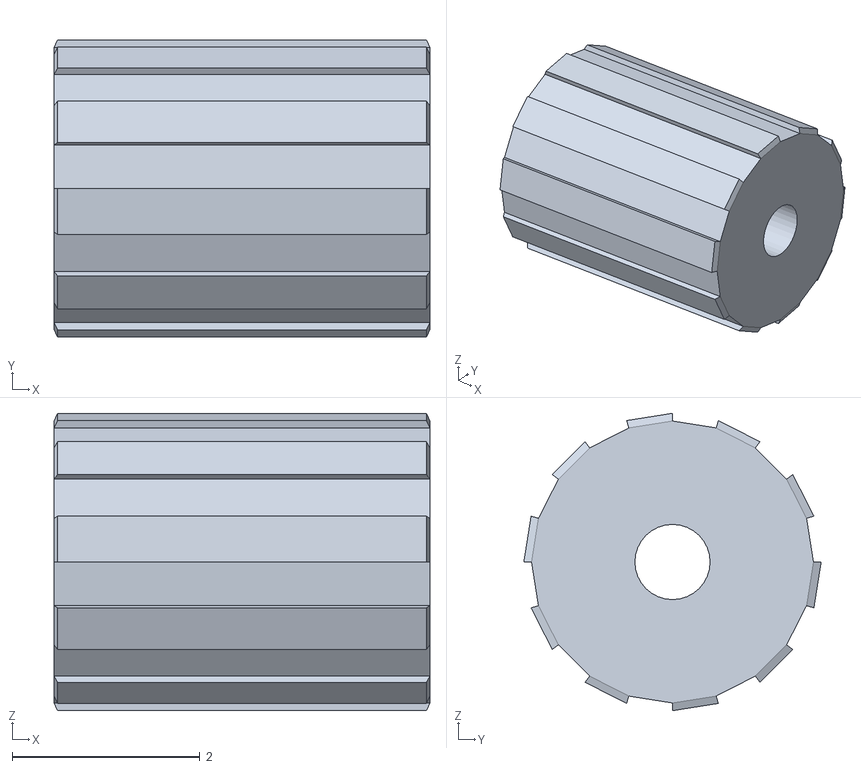
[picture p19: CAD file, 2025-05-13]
3D_Models/tube_support_empty.stl
4.00 x 3.16 x 3.16

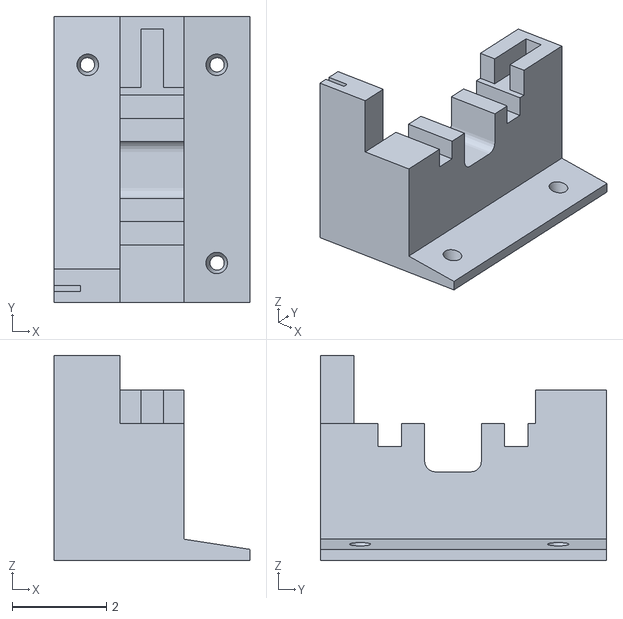
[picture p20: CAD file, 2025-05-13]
3D_Models/structural_frame_4.stl
4.14 x 6.05 x 4.35

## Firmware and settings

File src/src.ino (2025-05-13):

const int IN3 = 8; 
const int IN4 = 9;

const int IN1 = 6;   
const int IN2 = 7;   

const int ENCODER_A_PIN = 2;  
const int ENCODER_B_PIN = 3;  
volatile long encoderTicks = 0;

const int TICKS_PER_ROTATION = 611;  

const int TRIG_PIN = 4;
const int ECHO_PIN = A1;

const int S0 = 12;
const int S1 = 5;
const int S2 = 11;
const int S3 = 13;
const int OUT_COLOR = A0;

const int BUTTON_PIN = A2;

bool running = false;
bool last_button_state = LOW;
unsigned long ultimaApasare = 0;
const unsigned long INTERVAL_APASARE_LUNGA = 2000; 

int albRosu = 0, albVerde = 0, albAlbastru = 0;
int negruRosu = 0, negruVerde = 0, negruAlbastru = 0;
int albastruRosu = 0, albastruVerde = 0, albastruAlbastru = 0;
int portocaliuRosu = 0, portocaliuVerde = 0, portocaliuAlbastru = 0;

int etapaCalibrare = 0;  
bool senzorCalibrat = false;

int pragRosuMin = 0, pragRosuMax = 0;
int pragVerdeMin = 0, pragVerdeMax = 0;
int pragAlbastruMin = 0, pragAlbastruMax = 0;

void setup() {
  Serial.begin(9600);

  pinMode(S0, OUTPUT);
  pinMode(S1, OUTPUT);
  pinMode(S2, OUTPUT);
  pinMode(S3, OUTPUT);
  pinMode(OUT_COLOR, INPUT);
  digitalWrite(S0, HIGH);
  digitalWrite(S1, LOW);

  pinMode(IN3, OUTPUT);
  pinMode(IN4, OUTPUT);

  pinMode(IN1, OUTPUT); 
  pinMode(IN2, OUTPUT);
  
  pinMode(ENCODER_A_PIN, INPUT_PULLUP);
  pinMode(ENCODER_B_PIN, INPUT_PULLUP);
  attachInterrupt(digitalPinToInterrupt(ENCODER_A_PIN), countEncoderTick, RISING);

  pinMode(TRIG_PIN, OUTPUT);
  pinMode(ECHO_PIN, INPUT);

  pinMode(BUTTON_PIN, INPUT_PULLUP);
  
  Serial.println("Sistem initializat. Astept comanda de start.");
  Serial.println("tineti apasat butonul pentru 2 secunde pentru a incepe calibrarea senzorului de culoare.");
  delay(1000);
}

void loop() {
  bool current_button_state = digitalRead(BUTTON_PIN) == HIGH;
  
  if (current_button_state && !last_button_state) {
    ultimaApasare = millis();
  } 
  else if (!current_button_state && last_button_state) {
    if (millis() - ultimaApasare < INTERVAL_APASARE_LUNGA) {
      if (etapaCalibrare == 0) { 
        running = !running;
        if (running) {
          Serial.println("Sistem pornit");
        } else {
          Serial.println("Sistem oprit");
        }
      } else {
        procesareEtapaCalibrare();
      }
    }
  }
  
  if (current_button_state && (millis() - ultimaApasare > INTERVAL_APASARE_LUNGA)) {
    if (etapaCalibrare == 0 && !running) { 
      incepereCalibrare();
      ultimaApasare = millis(); 
    }
  }
  
  last_button_state = current_button_state;

  if (running) {
    motorBanda(true);
    float dist = masurareDistanta();
    
    if (millis() % 500 == 0) {
      Serial.print("Distanta: ");
      Serial.println(dist);
    }
    
    if (dist > 3.5 && dist < 5) { 
      motorBanda(false);
      Serial.println("Obiect detectat! Oprit banda.");
      Serial.println("Distanta:");
      Serial.println(dist);

      delay(200);
      
      String culoare = detecteazaCuloare();
      Serial.println("Culoare detectata: " + culoare);

      if (culoare == "portocaliu") {
        Serial.println("Activare paleta - directia stanga pentru obiect PORTOCALIU");
        paletaStanga();
        delay(1000); 
      } else if (culoare == "albastru") {
        Serial.println("Activare paleta - directia dreapta pentru obiect ALBASTRU");
        paletaDreapta();
        delay(1000); 
      } else {
        Serial.println("Culoare necunoscuta, reluare banda");
      }
      
      delay(1000); 
      motorBanda(true);
    }
  } else {
    motorBanda(false);
  }
}

void incepereCalibrare() {
  etapaCalibrare = 1;
  Serial.println("\n=== MOD CALIBRARE CULORI ===");
  Serial.println("Pozitionati senzorul pe obiectul ALB si apasati scurt butonul");
}

void procesareEtapaCalibrare() {
  switch (etapaCalibrare) {
    case 1: 
      digitalWrite(S2, LOW);
      digitalWrite(S3, LOW);
      delay(100);
      albRosu = pulseIn(OUT_COLOR, LOW);
      
      digitalWrite(S2, HIGH);
      digitalWrite(S3, HIGH);
      delay(100);
      albVerde = pulseIn(OUT_COLOR, LOW);
      
      digitalWrite(S2, LOW);
      digitalWrite(S3, HIGH);
      delay(100);
      albAlbastru = pulseIn(OUT_COLOR, LOW);
      
      Serial.println("Alb citit:");
      Serial.print("Rosu: "); Serial.println(albRosu);
      Serial.print("Verde: "); Serial.println(albVerde);
      Serial.print("Albastru: "); Serial.println(albAlbastru);
      
      Serial.println("\nAcum pozitionati senzorul pe obiectul NEGRU si apasati scurt butonul");
      etapaCalibrare = 2;
      break;
      
    case 2: 
      digitalWrite(S2, LOW);
      digitalWrite(S3, LOW);
      delay(100);
      negruRosu = pulseIn(OUT_COLOR, LOW);
      
      digitalWrite(S2, HIGH);
      digitalWrite(S3, HIGH);
      delay(100);
      negruVerde = pulseIn(OUT_COLOR, LOW);
      
      digitalWrite(S2, LOW);
      digitalWrite(S3, HIGH);
      delay(100);
      negruAlbastru = pulseIn(OUT_COLOR, LOW);
      
      Serial.println("Negru citit:");
      Serial.print("Rosu: "); Serial.println(negruRosu);
      Serial.print("Verde: "); Serial.println(negruVerde);
      Serial.print("Albastru: "); Serial.println(negruAlbastru);
      
      Serial.println("\nAcum pozitionati senzorul pe obiectul ALBASTRU si apasati scurt butonul");
      etapaCalibrare = 3;
      break;
      
    case 3: 
      digitalWrite(S2, LOW);
      digitalWrite(S3, LOW);
      delay(100);
      albastruRosu = pulseIn(OUT_COLOR, LOW);
      
      digitalWrite(S2, HIGH);
      digitalWrite(S3, HIGH);
      delay(100);
      albastruVerde = pulseIn(OUT_COLOR, LOW);
      
      digitalWrite(S2, LOW);
      digitalWrite(S3, HIGH);
      delay(100);
      albastruAlbastru = pulseIn(OUT_COLOR, LOW);
      
      Serial.println("Albastru citit:");
      Serial.print("Rosu: "); Serial.println(albastruRosu);
      Serial.print("Verde: "); Serial.println(albastruVerde);
      Serial.print("Albastru: "); Serial.println(albastruAlbastru);
      
      Serial.println("\nAcum pozitionati senzorul pe obiectul PORTOCALIU si apasati scurt butonul");
      etapaCalibrare = 4;
      break;
      
    case 4: 
      digitalWrite(S2, LOW);
      digitalWrite(S3, LOW);
      delay(100);
      portocaliuRosu = pulseIn(OUT_COLOR, LOW);
      
      digitalWrite(S2, HIGH);
      digitalWrite(S3, HIGH);
      delay(100);
      portocaliuVerde = pulseIn(OUT_COLOR, LOW);
      
      digitalWrite(S2, LOW);
      digitalWrite(S3, HIGH);
      delay(100);
      portocaliuAlbastru = pulseIn(OUT_COLOR, LOW);
      
      Serial.println("Portocaliu citit:");
      Serial.print("Rosu: "); Serial.println(portocaliuRosu);
      Serial.print("Verde: "); Serial.println(portocaliuVerde);
      Serial.print("Albastru: "); Serial.println(portocaliuAlbastru);
      
      int difRosu = abs(albastruRosu - portocaliuRosu);
      int difVerde = abs(albastruVerde - portocaliuVerde);
      int difAlbastru = abs(albastruAlbastru - portocaliuAlbastru);
      
      pragRosuMin = albRosu;  
      pragRosuMax = negruRosu;  
      
      pragVerdeMin = albVerde;
      pragVerdeMax = negruVerde;
      
      pragAlbastruMin = albAlbastru;
      pragAlbastruMax = negruAlbastru;
      
      Serial.println("\n=== CALIBRARE COMPLETa ===");
      Serial.println("Valorile de calibrare:");
      Serial.println("Alb - Rosu: " + String(albRosu) + ", Verde: " + String(albVerde) + ", Albastru: " + String(albAlbastru));
      Serial.println("Negru - Rosu: " + String(negruRosu) + ", Verde: " + String(negruVerde) + ", Albastru: " + String(negruAlbastru));
      Serial.println("Portocaliu - Rosu: " + String(portocaliuRosu) + ", Verde: " + String(portocaliuVerde) + ", Albastru: " + String(portocaliuAlbastru));
      Serial.println("Albastru - Rosu: " + String(albastruRosu) + ", Verde: " + String(albastruVerde) + ", Albastru: " + String(albastruAlbastru));
      
      Serial.println("\nDiferente intre culori:");
      Serial.println("Diferenta Rosu: " + String(difRosu));
      Serial.println("Diferenta Verde: " + String(difVerde));
      Serial.println("Diferenta Albastru: " + String(difAlbastru));
      
      etapaCalibrare = 0; 
      senzorCalibrat = true; 
      Serial.println("Puteti porni sistemul prin apasare scurta a butonului");
      break;
  }
}

void motorBanda(bool pornit) {
  if (pornit) {
    digitalWrite(IN3, LOW);
    digitalWrite(IN4, HIGH);
  } else {
    digitalWrite(IN3, LOW);
    digitalWrite(IN4, LOW);
  }
}

void countEncoderTick() {
  if (digitalRead(ENCODER_B_PIN) == HIGH) {
    encoderTicks++;  
  } else {
    encoderTicks--;  
  }
}

void paletaStanga() {
  Serial.println("Stanga - rotatie completa");
  long targetTicks = encoderTicks + TICKS_PER_ROTATION;  
  
  digitalWrite(IN1, HIGH);
  digitalWrite(IN2, LOW);
  
  unsigned long startTime = millis();
  
  while (encoderTicks < targetTicks) {
    if (millis() % 100 == 0) {  
      Serial.print("Encoder count: ");
      Serial.print(encoderTicks);
      Serial.print(" / Target: ");
      Serial.println(targetTicks);
    }
    
    if (millis() - startTime > 5000) {
      Serial.println("Timeout - oprire fortata");
      break;
    }
    
    delay(5);  
  }
  
  Serial.println("Rotatie completa finalizata");
  oprirePaleta();
}

void paletaDreapta() {
  Serial.println("Dreapta - rotatie completa");
  long targetTicks = encoderTicks - TICKS_PER_ROTATION;  
  
  digitalWrite(IN1, LOW);
  digitalWrite(IN2, HIGH);
  
  unsigned long startTime = millis();
  
  while (encoderTicks > targetTicks) {
    if (millis() % 100 == 0) {  
      Serial.print("Encoder count: ");
      Serial.print(encoderTicks);
      Serial.print(" / Target: ");
      Serial.println(targetTicks);
    }
    
    if (millis() - startTime > 5000) {
      Serial.println("Timeout - oprire fortata");
      break;
    }
    
    delay(5);  
  }
  
  Serial.println("Rotatie completa finalizata");
  oprirePaleta();
}

void oprirePaleta() {
  digitalWrite(IN1, LOW);
  digitalWrite(IN2, LOW);
}

float masurareDistanta() {
  digitalWrite(TRIG_PIN, LOW);
  delayMicroseconds(2);
  digitalWrite(TRIG_PIN, HIGH);
  delayMicroseconds(10);
  digitalWrite(TRIG_PIN, LOW);
  long durata = pulseIn(ECHO_PIN, HIGH, 20000);
  float dist = durata * 0.034 / 2;
  return dist;
}

String detecteazaCuloare() {
  digitalWrite(S2, LOW);
  digitalWrite(S3, LOW);
  delay(50);
  int rosu = pulseIn(OUT_COLOR, LOW);
  
  digitalWrite(S2, HIGH);
  digitalWrite(S3, HIGH);
  delay(50);
  int verde = pulseIn(OUT_COLOR, LOW);
  
  digitalWrite(S2, LOW);
  digitalWrite(S3, HIGH);
  delay(50);
  int albastru = pulseIn(OUT_COLOR, LOW);
  
  Serial.print("Citire curenta - Rosu: "); Serial.print(rosu);
  Serial.print(", Verde: "); Serial.print(verde);
  Serial.print(", Albastru: "); Serial.println(albastru);
  
  if (senzorCalibrat) {
    long distantaPortocaliu = sq(rosu - portocaliuRosu) + 
                             sq(verde - portocaliuVerde) + 
                             sq(albastru - portocaliuAlbastru);
    
    long distantaAlbastru = sq(rosu - albastruRosu) + 
                           sq(verde - albastruVerde) + 
                           sq(albastru - albastruAlbastru);
    
    bool esteInIntervalRosu = (rosu >= pragRosuMin && rosu <= pragRosuMax);
    bool esteInIntervalVerde = (verde >= pragVerdeMin && verde <= pragVerdeMax);
    bool esteInIntervalAlbastru = (albastru >= pragAlbastruMin && albastru <= pragAlbastruMax);
    
    Serial.print("Distanta fata de portocaliu: "); Serial.println(distantaPortocaliu);
    Serial.print("Distanta fata de albastru: "); Serial.println(distantaAlbastru);
    
    if (!esteInIntervalRosu || !esteInIntervalVerde || !esteInIntervalAlbastru) {
      return "necunoscut"; 
    }
    
    if (distantaPortocaliu < distantaAlbastru) {
      return "portocaliu";
    } else {
      return "albastru";
    }
  } else {
    if (rosu < 340 && verde > 400 && albastru > 200) return "portocaliu";
    else if (rosu > 340 && verde < 400 && albastru < 300) return "albastru";
    else return "necunoscut";
  }
}
